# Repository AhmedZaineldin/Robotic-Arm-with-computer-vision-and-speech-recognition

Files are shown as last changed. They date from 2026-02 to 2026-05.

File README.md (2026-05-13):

# 🦾 Robotic Arm for Surgical Assistance







A **6-DOF (Degree of Freedom) robotic arm** designed for surgical assistance, developed as a Final Year Project at the **Faculty of Engineering, Alexandria University — Biomedical Engineering Department**.

The arm integrates **YOLOv8 object detection**, **real-time speech recognition**, and **hand gesture control** to allow surgeons to retrieve surgical tools hands-free, improving sterility, efficiency, and precision in the operating room.

---

## 👥 Team

| Name | ID |
|---|---|
| Ahmed Zaineldin | 7337 |
| Omar Yasser | 7437 |
| Khaled Ahmed | 7463 |
| Moustafa Farouk | 7590 |
| Malak Sherif | 7701 |
| Laylan Maged | 7828 |
| Jana Abdellatif | 7659 |
| Mohamed Sherif | 7511 |

**Supervised by:** Dr. Taher Awad · Dr. Mohamed Abdelnaeem · Dr. Mahmoud Omar

---

## 📸 Demo

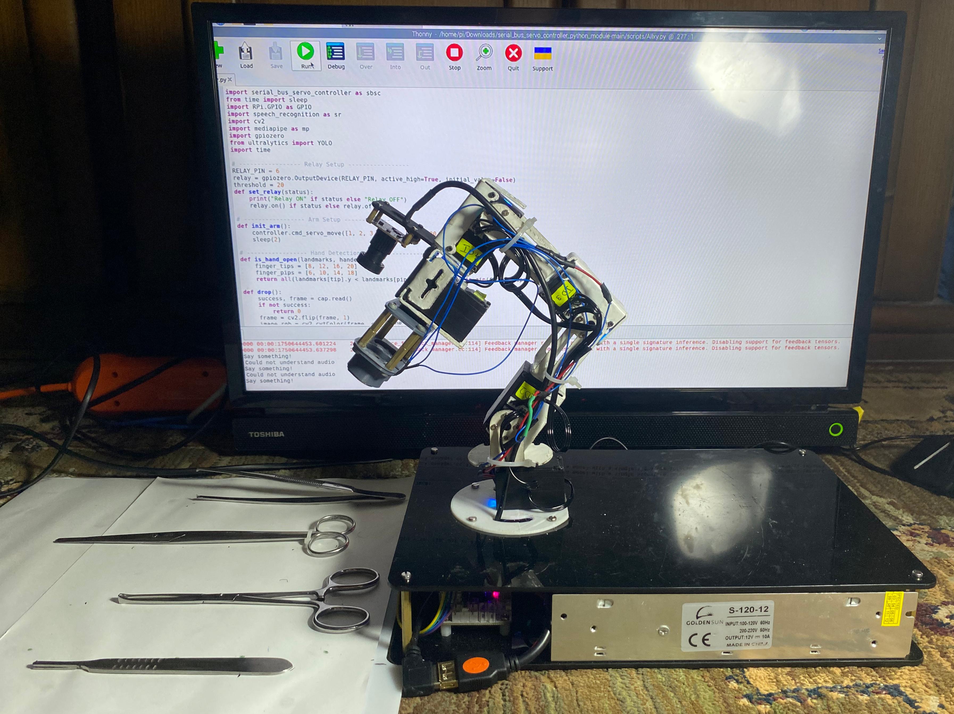
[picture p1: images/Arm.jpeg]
Demo

---

## ✨ Features

- 🎤 **Voice-Controlled Tool Selection** — Surgeons request tools by name; speech recognition identifies the command using Google's Speech Recognition API
- 👁️ **YOLOv8 Object Detection** — Detects and localizes surgical tools (forceps, scalpel, iris scissors, hemostat) in real-time from a live camera feed
- ✋ **Hand Gesture Release** — An open-hand gesture (detected via MediaPipe) triggers the electromagnet to release the tool to the surgeon
- 🤖 **6-DOF Articulated Arm** — CNC-cut iron frame with 5× LX-15D Serial Bus Servos and full kinematics support
- 🧲 **Electromagnetic End Effector** — Dual electromagnets controlled via a relay module for contactless tool pickup and release
- 🔁 **Multithreaded Pipeline** — Vision, speech, and motor control run concurrently for real-time responsiveness

---

## 🛠️ Hardware

| Component | Details |
|---|---|
| Microcontroller | Raspberry Pi 5 (4GB, 2.4GHz Quad-Core Cortex-A76) |
| Servo Motors | 7× LX-15D Serial Bus Servo (15 kg/cm torque, 240° range, real-time feedback) |
| Servo Controller | Hiwonder Serial Bus Servo Controller (STM32 ARM Cortex-M3) |
| Camera | USB Camera Module — 640×480 VGA, 30fps, 130° wide-angle |
| Microphone | ZAFFIRO USB Microphone |
| End Effector | Dual DC5V Electric Lifting Magnets (2.5–3 kg holding force each) |
| Relay Module | 5V Single-Channel Relay with Optocoupler Isolation |
| Power Supply | 12V 10A Switching Power Supply |
| Step-Down Converter | XL4016 DC-DC Buck Converter (12V → 7.4V for servos) |
| Structure | CNC-cut iron frame (L1=8cm, L2=8cm, L3=10cm) |
| Electronics Base | Acrylic enclosure housing Raspberry Pi and power components |

---

## 💻 Software & Libraries

```
Python 3.x
ultralytics          # YOLOv8 object detection
opencv-python        # Video capture and frame processing
mediapipe            # Real-time hand landmark detection
SpeechRecognition    # Google Speech-to-Text
pyaudio              # Microphone audio input
serial_bus_servo_controller  # Hiwonder servo communication (UART)
gpiozero             # Raspberry Pi GPIO / relay control
RPi.GPIO
```

---

## 🧠 How It Works

```
Surgeon speaks tool name (e.g. "forceps")
            │
            ▼
   Google Speech Recognition
            │
            ▼
  YOLOv8 detects tool in camera feed
  → calculates X-position of bounding box
            │
            ▼
  X-position mapped to one of 4 workspace zones
  → servo PWM angles selected for that zone
            │
            ▼
  Raspberry Pi sends commands via UART
  → LX-15D servos move arm to tool location
            │
            ▼
  Relay activates electromagnet → picks up tool
  → arm moves to handoff position above surgeon
            │
            ▼
  MediaPipe detects open hand gesture (25 consecutive frames)
  → relay deactivates electromagnet → tool released
            │
            ▼
  Arm returns to home position
```

---

## 🚀 Getting Started

### 1. Clone the Repository

```bash
git clone https://github.com/AhmedZaineldin/Robotic-Arm-with-computer-vision-and-speech-recognition.git
cd Robotic-Arm-with-computer-vision-and-speech-recognition
```

### 2. Install Dependencies

```bash
pip install ultralytics opencv-python mediapipe SpeechRecognition pyaudio gpiozero RPi.GPIO
```

> Make sure the `serial_bus_servo_controller` library is installed per the [Hiwonder documentation](https://www.hiwonder.com).

### 3. Add the Trained YOLO Model

Place your custom-trained weights file (`ourdata.pt`) in the project root. This model was trained on 4,257 augmented images across 4 surgical tool classes: **forceps**, **scalpel**, **iris scissors**, and **hemostat**.

### 4. Connect Hardware

- Connect the Hiwonder Servo Controller to the Raspberry Pi via USB (`/dev/ttyUSB0`)
- Connect the relay module to **GPIO Pin 6**
- Connect the USB camera and ZAFFIRO microphone

### 5. Run

```bash
python main.py
```

---

## 🎤 Supported Voice Commands

| Say | Tool Retrieved |
|---|---|
| `"forceps"` / `"forces"` / `"46"` | Forceps |
| `"scalpel"` / `"scalp"` / `"skeleton"` | Scalpel |
| `"iris"` | Iris Scissors |
| `"hemostat"` / `"thermostate"` / `"Hampstead"` | Hemostat |

> Phonetic variants are included to handle common speech recognition mismatches.

---

## 🤖 Machine Learning — YOLOv8 Custom Model

| Detail | Value |
|---|---|
| Architecture | YOLOv8-small (`yolov8s.yaml`) |
| Dataset Size | 1,419 original images → **4,257 after augmentation** |
| Classes | forceps · scalpel · iris · hemostat |
| Annotation Tool | Roboflow (YOLO format) |
| Accuracy | ~80% mAP |
| Training Hardware | GPU (CUDA, `device=0`) |
| Confidence Threshold | 0.4 |
| Input Size | 256×256 |

Augmentation techniques: rotation, scaling, flipping, and color adjustment.

---

## 📐 Design & Kinematics

- **6 DOF** with Denavit-Hartenberg (DH) parameterization
- Forward kinematics validated using **Peter Corke's MATLAB Robotics Toolbox**
- Working area visualized in **AutoCAD** and verified with Python simulation
- Link lengths: L1 = 8 cm · L2 = 8 cm · L3 = 10 cm
- Force analysis performed for worst-case (fully extended arm, 500g load)
- Material selected: **CNC-cut iron** — chosen over aluminum and PLA for superior reliability and durability

---

## 📁 Project Structure

```
├── main.py                  # Entry point — voice, vision, and arm control
├── ourdata.pt               # Custom YOLOv8 trained weights
├── data.yaml                # YOLOv8 dataset configuration
├── train.py                 # Model training script
└── README.md
```

---

## 🔭 Future Improvements

- Complete inverse kinematics integration for smoother, more flexible motion
- Expand the surgical tool dataset to cover more instrument classes
- Implement AI-driven adaptive control with real-time feedback learning
- Add force feedback and collision detection for enhanced safety
- Develop a GUI for surgeons to customize arm behavior
- Explore 5G telemedicine integration for remote surgical assistance

---

## 📖 Citation

If you use this project in your research, please cite it as:

**APA:**
Ahmed Zaineldin, Yasser, O., Ahmed, K., Farouk, M., Sherif, M., Maged, L., Abdellatif, J., & Sherif, M. (2026). AhmedZaineldin/Robotic-Arm-with-computer-vision-and-speech-recognition: v1.0.0 — Surgical Assistance Robotic Arm. Zenodo. https://doi.org/10.5281/zenodo.19753079

**BibTeX:**
```bibtex
@software{ahmed_zaineldin_2026_19753079,
  author       = {Ahmed Zaineldin and
                  Yasser, Omar and
                  Ahmed, Khaled and
                  Farouk, Moustafa and
                  Sherif, Malak and
                  Maged, Laylan and
                  Abdellatif, Jana and
                  Sherif, Mohamed},
  title        = {AhmedZaineldin/Robotic-Arm-with-computer-vision-
                   and-speech-recognition: v1.0.0 — Surgical
                   Assistance Robotic Arm
                  },
  month        = apr,
  year         = 2026,
  publisher    = {Zenodo},
  doi          = {10.5281/zenodo.19753079},
  url          = {https://doi.org/10.5281/zenodo.19753079},
}
```



---

## 🏫 Institution

**Faculty of Engineering — Alexandria University**  
Biomedical Engineering Department — Final Year Project

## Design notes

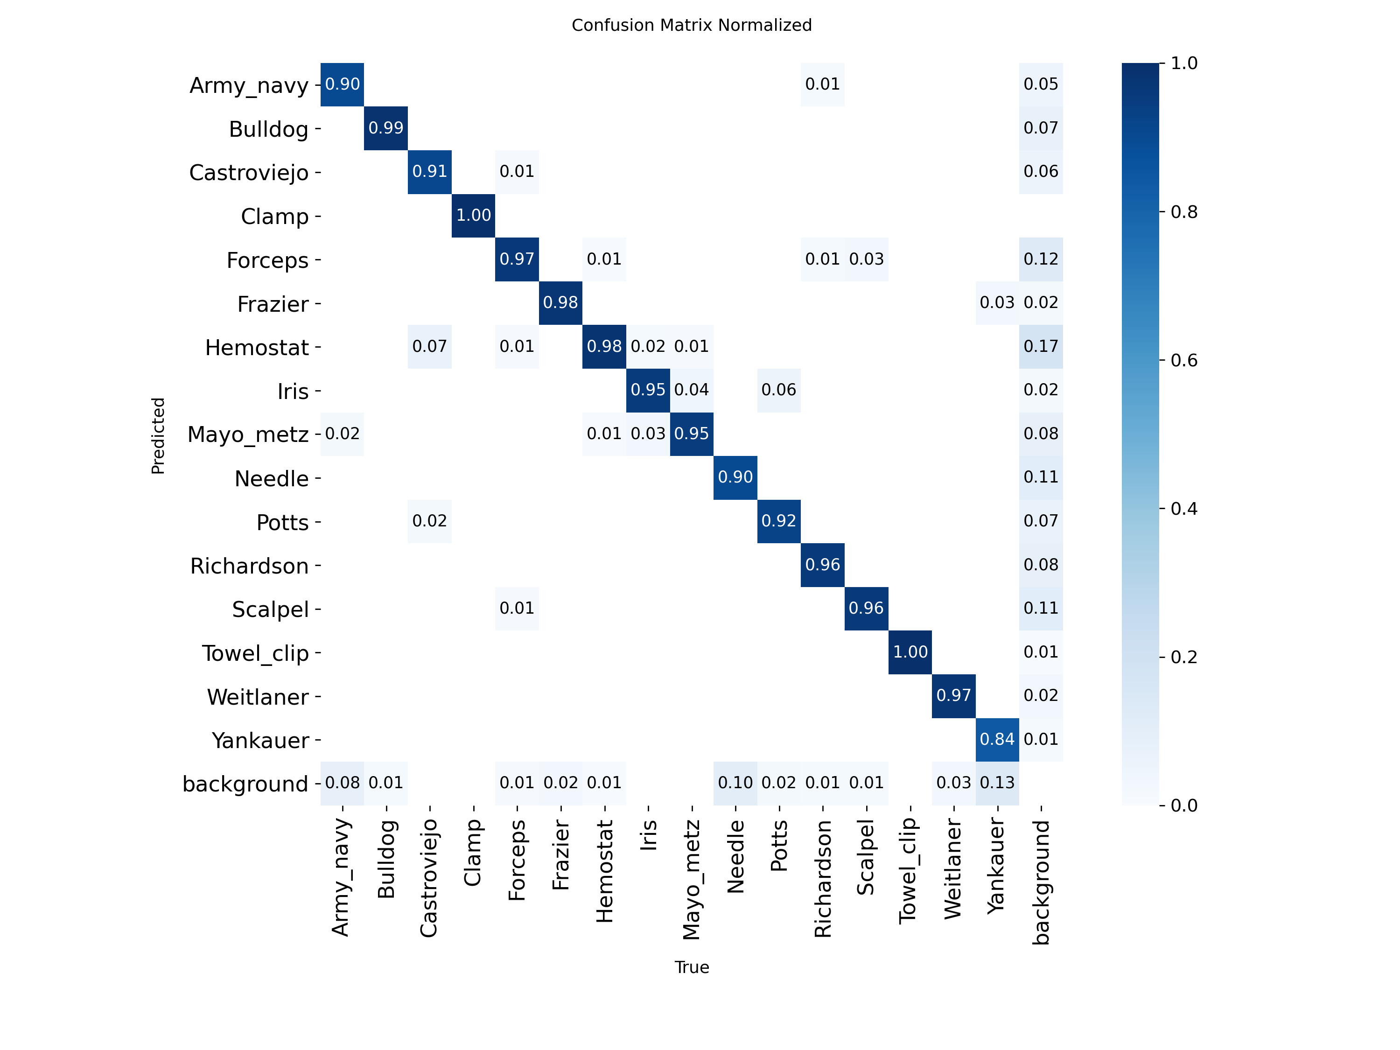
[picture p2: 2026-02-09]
Model/confusion_matrix_normalized.png

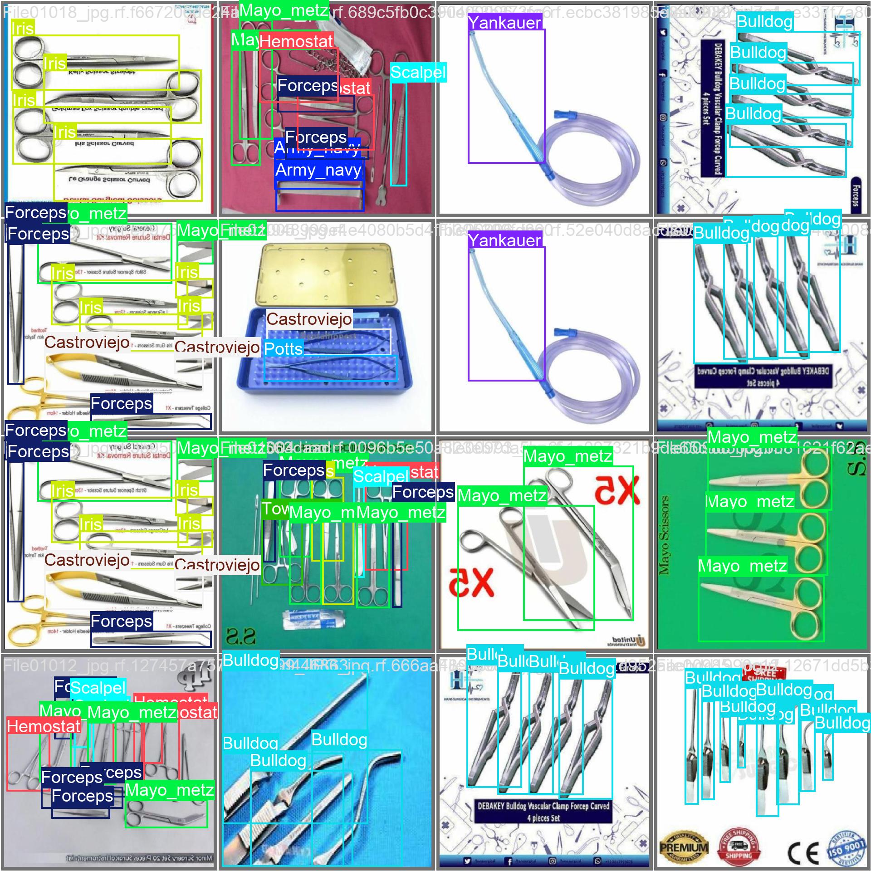
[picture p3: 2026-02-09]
Model/val_batch0_labels.jpg

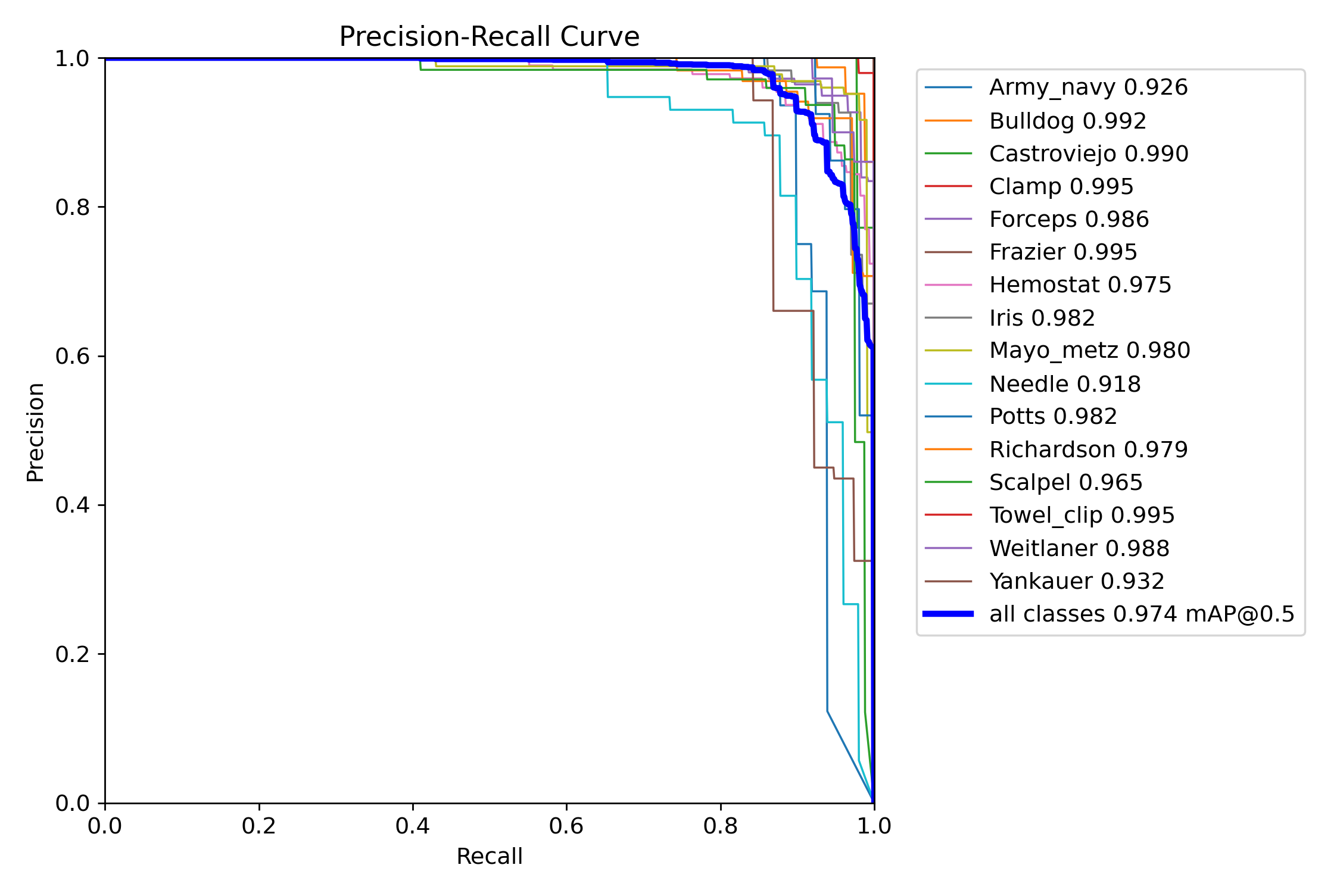
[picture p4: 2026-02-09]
Model/PR_curve.png

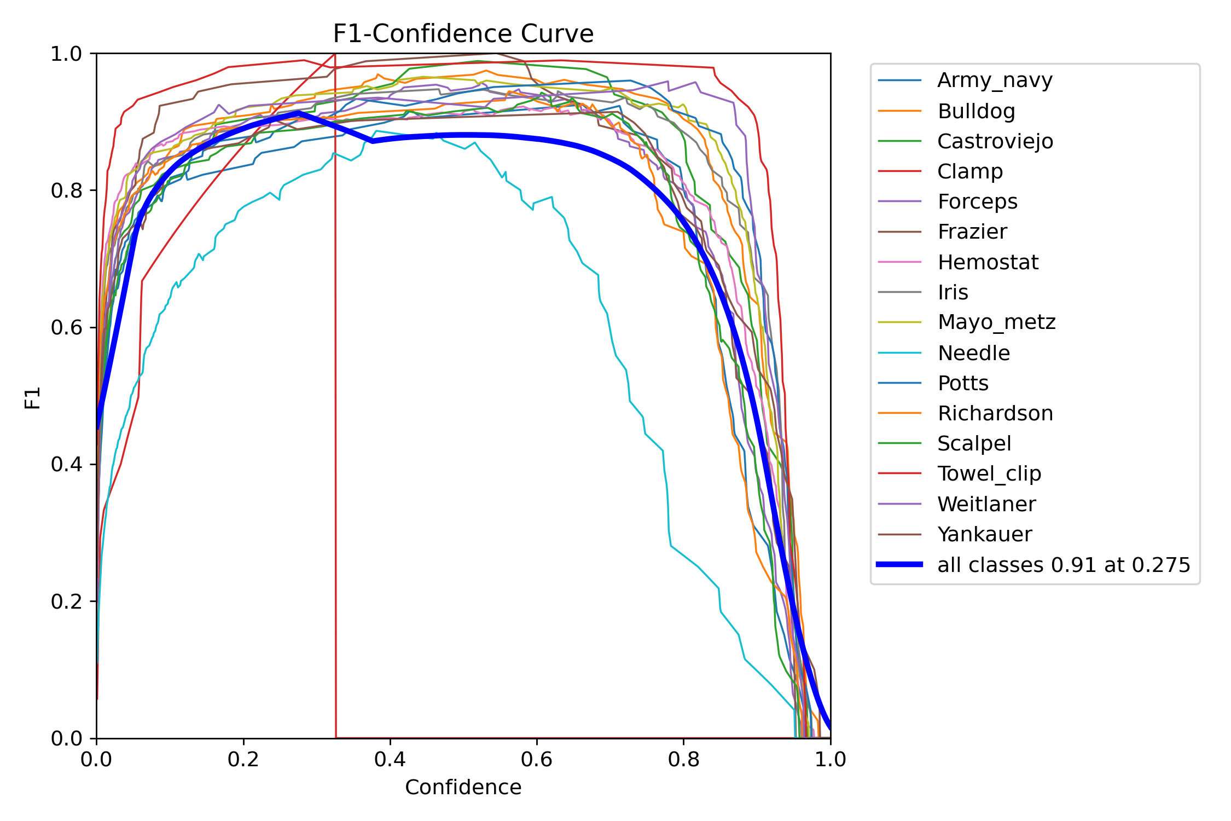
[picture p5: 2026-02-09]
Model/F1_curve.png

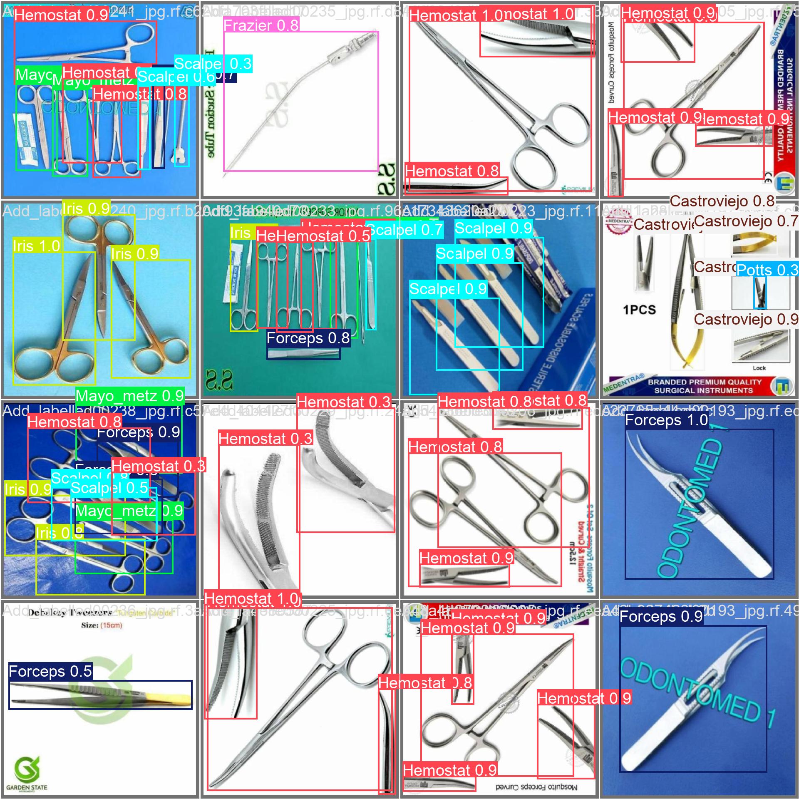
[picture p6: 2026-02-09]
Model/val_batch2_pred.jpg

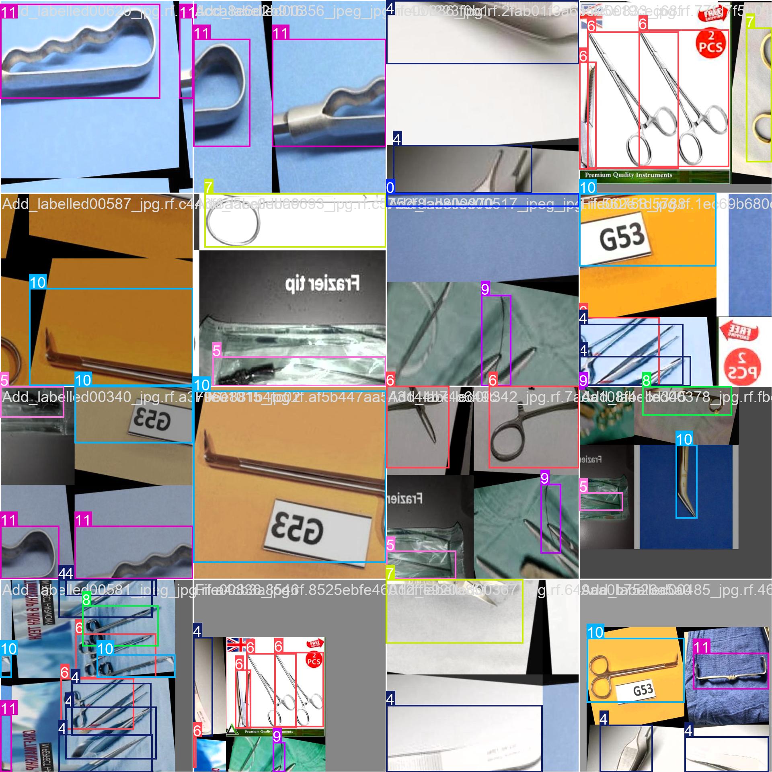
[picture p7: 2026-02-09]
Model/train_batch2.jpg

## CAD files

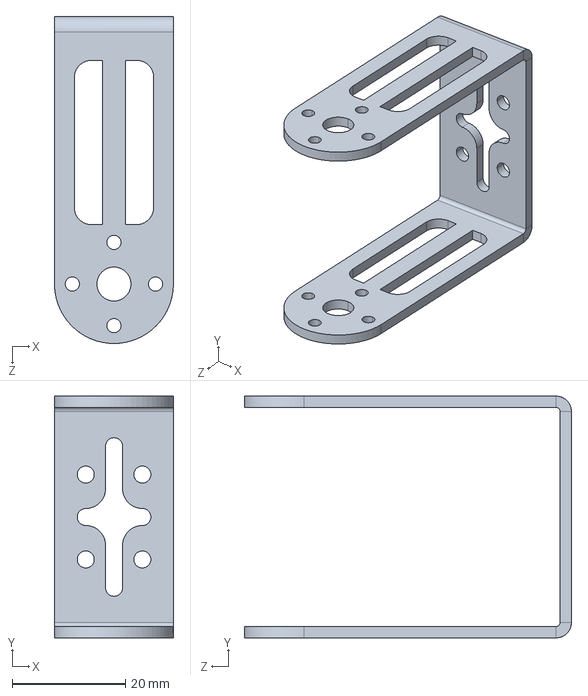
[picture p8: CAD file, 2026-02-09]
Design/bracket 2.STEP
21.0 x 42.7 x 57.8 mm

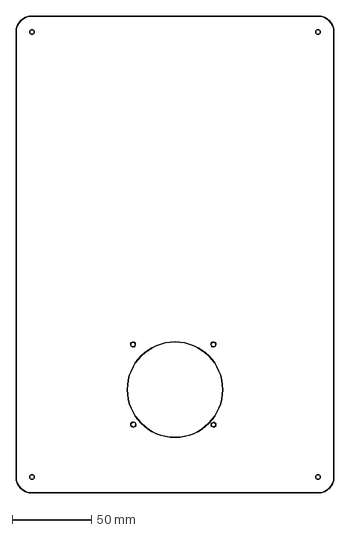
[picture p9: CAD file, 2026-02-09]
Design/upper base.DXF
200.0 x 300.0 mm

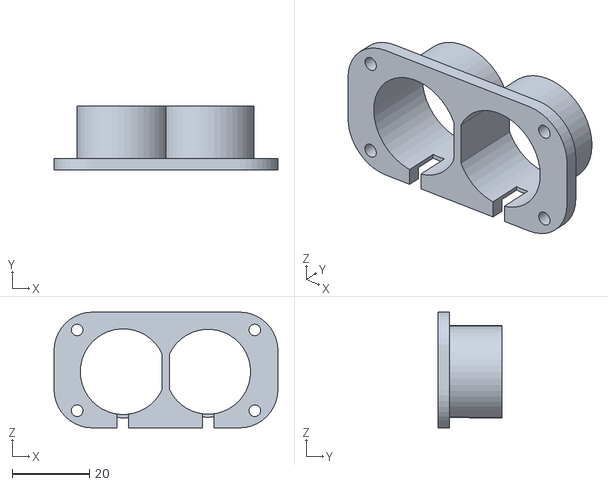
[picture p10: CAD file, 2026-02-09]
Design/Part2 (2 magnets).STL
58.0 x 16.5 x 30.0

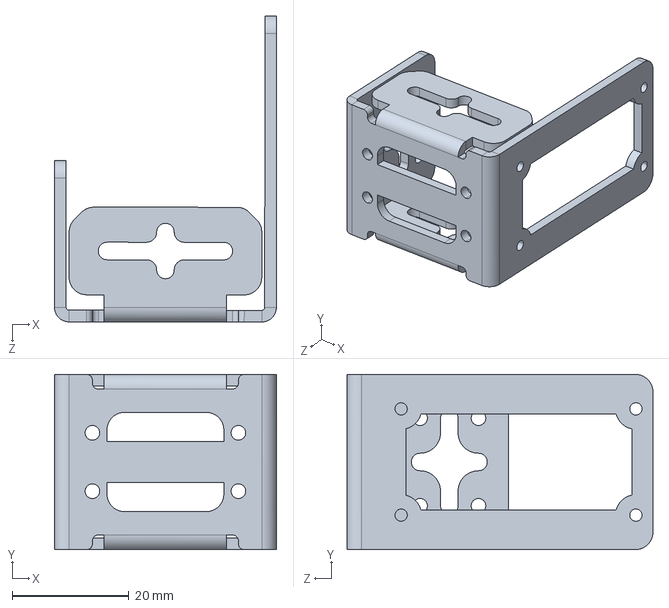
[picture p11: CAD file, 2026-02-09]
Design/bracket 4.STEP
38.0 x 30.0 x 52.4 mm

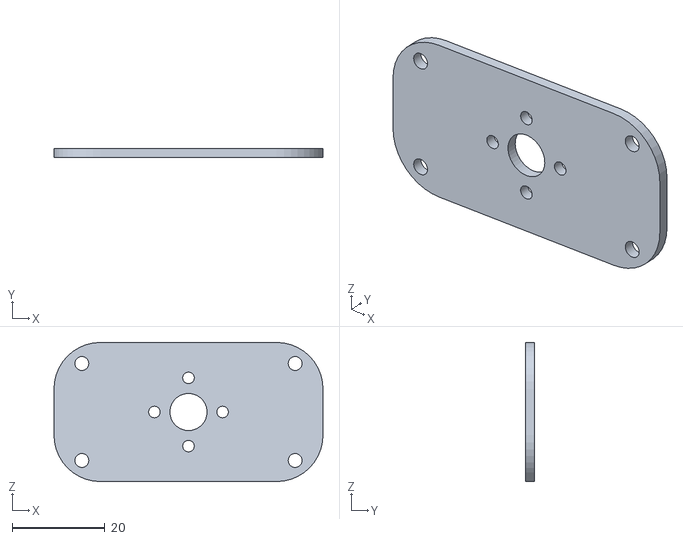
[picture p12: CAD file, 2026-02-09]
Design/Part1 (2magnets).STL
58.0 x 2.00 x 30.0

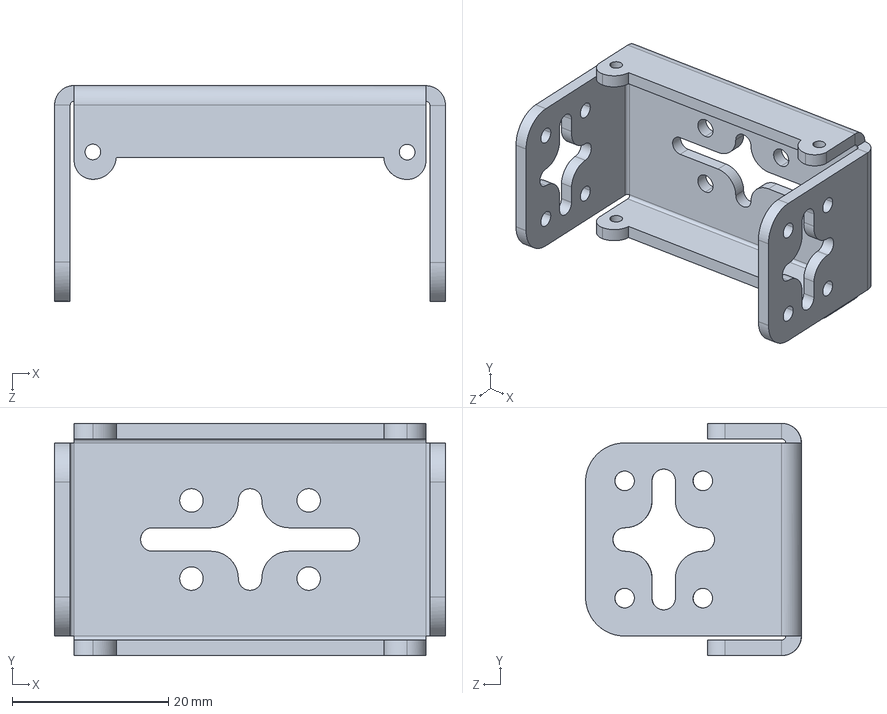
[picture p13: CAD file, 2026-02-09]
Design/bracket 3.STEP
50.0 x 29.7 x 27.6 mm

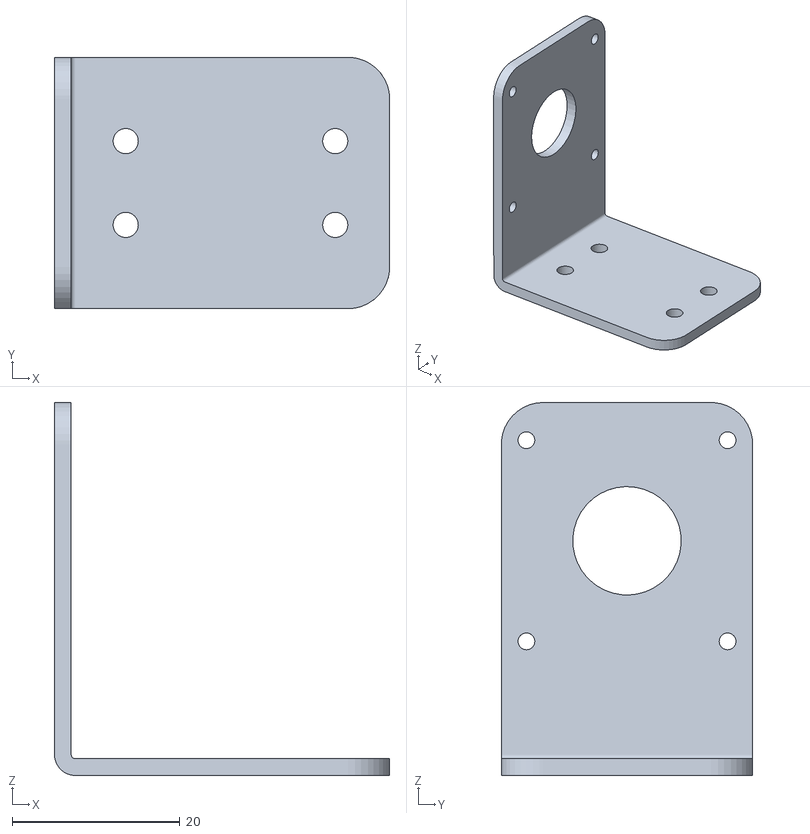
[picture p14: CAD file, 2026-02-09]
Design/l connector camera.STL
40.0 x 30.0 x 44.5

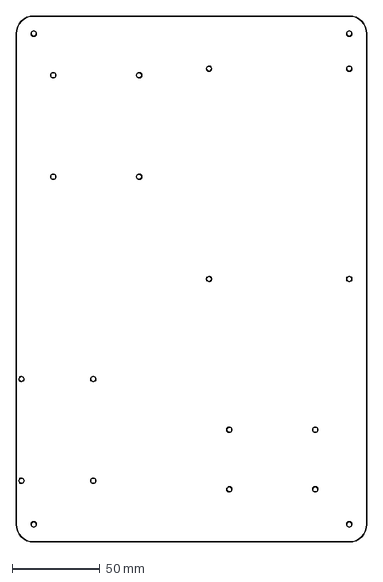
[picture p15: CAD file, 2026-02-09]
Design/lower base.DXF
200.0 x 300.0 mm

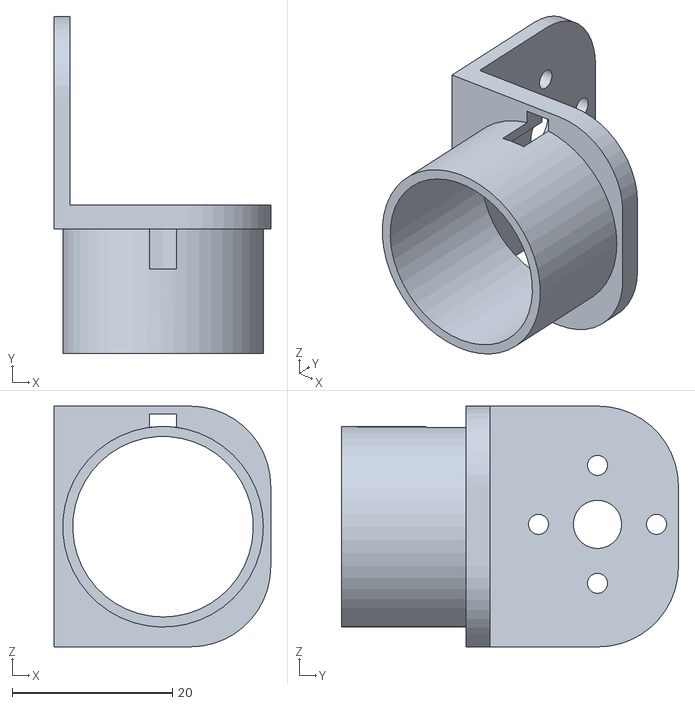
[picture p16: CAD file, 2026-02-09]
Design/L for magnet new.STL
27.0 x 42.0 x 30.0

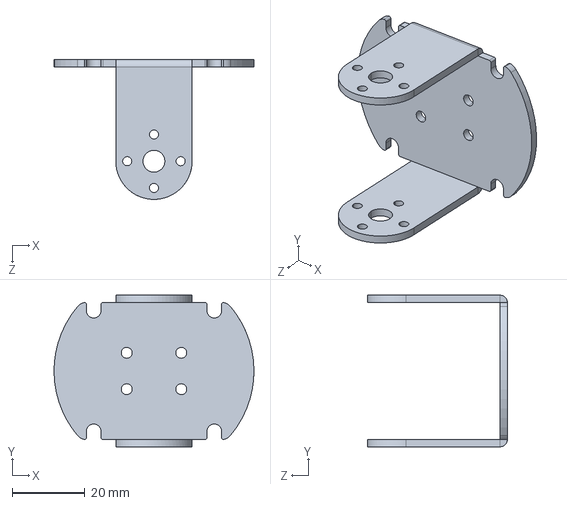
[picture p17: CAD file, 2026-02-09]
Design/bracket 1.STEP
55.0 x 41.7 x 38.4 mm

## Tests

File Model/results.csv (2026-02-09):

epoch | time | train/box_loss | train/cls_loss | train/dfl_loss | metrics/precision(B) | metrics/recall(B) | metrics/mAP50(B) | metrics/mAP50-95(B) | val/box_loss | val/cls_loss | val/dfl_loss | lr/pg0 | lr/pg1 | lr/pg2
1 | 4292.4 | 3.17627 | 4.67673 | 3.77692 | 0.00143 | 0.24146 | 0.00468 | 0.00131 | 3.40607 | 3.88931 | 3.69419 | 0.0683786 | 0.00166428 | 0.00166428
2 | 6895.83 | 2.41894 | 4.01392 | 2.98061 | 0.23045 | 0.06924 | 0.0285 | 0.00959 | 2.54358 | 3.60654 | 3.10198 | 0.036657 | 0.00327599 | 0.00327599
3 | 10023.6 | 1.92618 | 3.48314 | 2.44144 | 0.14296 | 0.13374 | 0.06661 | 0.02984 | 1.94774 | 3.07313 | 2.54637 | 0.00488038 | 0.00483269 | 0.00483269
4 | 13083.6 | 1.68392 | 3.1479 | 2.17917 | 0.17525 | 0.21114 | 0.11741 | 0.061 | 1.72216 | 2.68887 | 2.28006 | 0.0047525 | 0.0047525 | 0.0047525
5 | 15793.1 | 1.54676 | 2.90332 | 2.04278 | 0.16283 | 0.2601 | 0.15393 | 0.08722 | 1.60573 | 2.48419 | 2.1158 | 0.00467 | 0.00467 | 0.00467
6 | 19954.1 | 1.46417 | 2.69036 | 1.94351 | 0.23027 | 0.3256 | 0.24353 | 0.14433 | 1.44503 | 2.21176 | 1.94491 | 0.0045875 | 0.0045875 | 0.0045875
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
